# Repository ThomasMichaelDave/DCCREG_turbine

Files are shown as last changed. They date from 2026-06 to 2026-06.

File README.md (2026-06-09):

# Variable Capacitor → Symmetric Bennet Doubler

A browser-based design tool. A parametric **sectored-disc + ring** capacitor plate, whose geometry, plate gap, and dielectric set the **rotor-capacitance extremes** that drive a **Symmetric Bennet Doubler** switched-capacitor solver. One self-contained `index.html`, no build step.

> **Status.** Host doubler simulator: working, self-tested. **Block C-I** (geometry → rotor-cap front end): *implemented and self-tested* in `index.html` — see `docs/` for the brief and `CHANGELOG.md` for the audit trail.

---

## Working discipline

Every substantive claim in the docs (and modelling choices in code comments) carries a tier tag:

- **[OC] Operational Core** — standard, derivable physics/math; true independent of this project.
- **[IR] Interpretive Reading** — a modelling / engineering choice; internally consistent, chosen rather than forced.
- **[RH] Resonance / Heuristic** — suggestive, not load-bearing.

Keep the tiers honest; do not let **[RH]** drift into **[OC]**. Correct openly when rigor demands and record it in `CHANGELOG.md`.

The *methodology* (tier tags, versioned consolidation, open-fork tracking, symbol hygiene, handoff README) is adapted from the **DCCREG programme conventions**. **The physics in this repo is entirely mainstream** — parallel-plate capacitance, rotary variable capacitors, and the Bennet charge doubler. **No DCCREG theory is included or required.**

---

## Repo map

| Path | Role |
|:--|:--|
| `index.html` | The app — Symmetric Bennet Doubler 4-node simulator (**host**; Blocks C-I and M extend it) |
| `docs/brief-blockC1-geometry-to-rotorcap.md` | Implementation brief for the geometry → rotor-cap module |
| `docs/commutator-design.md` | Switching design — physical realisation of the solver's diodes D1–D4 (rotary commutator); geometry frozen, transfer model open |
| `docs/brief-blockM-rotor-mechanical-core.md` | Implementation brief for the rotor mechanical core (quadricone + shaft + void + disc) |
| `docs/brief-blockR-central-resonator.md` | Implementation brief for the central resonator (conical coil + inter-electrode capacitor) |
| `docs/report-tool-functioning.md` | Standalone functional report on the whole tool |
| `reference/SectoredDiscCalculator.jsx` | Area-math source to **port** into `index.html` (reference only — not built/served) |
| `CONVENTIONS.md` | Epistemic tags + symbol-hygiene table + host-field-id mapping |
| `CHANGELOG.md` | Human-readable audit trail (git owns the authoritative history) |
| `CLAUDE.md` | Handoff + guardrails for the Claude Code agent |

## Read order (fresh agent or contributor)

`README.md` → `CONVENTIONS.md` → `docs/brief-blockC1-geometry-to-rotorcap.md` → `index.html` (host) → `docs/commutator-design.md` (switching realisation) → `reference/SectoredDiscCalculator.jsx` (math to port).

## Run

Open `index.html` in any modern browser. No build, no server, no dependencies. State is shareable via the URL hash ("copy share-url").

## Current task

Blocks **C-I** (geometry → rotor caps) and **M** (rotor mechanical core) are implemented in `index.html`. Both follow the producer/consumer discipline: C-I drives the rotor caps; M is an independent producer (geometry + cross-section readout) that never touches `solveDoubler4`.

## Verification

The page self-tests on load (engine badge + expandable self-test table). The gate is deterministic: the four original solver tests + swap symmetry, the C-I plate tests (dry-air ε_r ≈ 1.000576; fixed-geometry capacitance), and the Block M tests (`hubDia = 197 mm`; void-partition identity; `keyLenFor(35) → DIN 56`) must all pass — badge reads "engine verified".

## Versioning policy

Git owns history. `CHANGELOG.md` is the human-readable audit trail. **Flat filenames — no `_vNN` suffixes and no in-file revision tables** (git replaces both). Conventional-commit style suggested: `feat:`, `fix:`, `docs:`, `test:`, `refactor:`.

## Open forks

Carried from brief §7: field-range policy (raise-max vs clamp-and-warn); hash round-trip for non-numeric controls; solid-dielectric rotary realisability; optional θ-sweep visualisation; dielectric-strength / safe-voltage bound (the genuine next block); fringing correction.

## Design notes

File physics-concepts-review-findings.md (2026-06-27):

# Findings — physics-concepts review → **REPO MAINSTREAM · ION-SIPHON HAS ONE LOAD-BEARING CONSERVATION GAP**

**Branch** `claude/physics-concepts-review-wp81n4`.
**Scope:** scrutinise the load-bearing physics against mainstream electromagnetism / thermodynamics.
Two bodies reviewed: (1) the existing repo (Bennet doubler + variable-capacitor front end + energy-balance
findings); (2) the uploaded `ion_siphon_package.zip` (electret-capillary ion siphon).
**Tier tags** as in `CONVENTIONS.md`: **[OC]** standard physics · **[IR]** modelling choice · **[RH]** heuristic.

**Verdict line:** the repo's electrostatic-machine physics is **mainstream and internally honest**; the
ion-siphon derivation is mostly sound **but its "continuous mode" rests on a non-depleting electret driving a
steady closed-loop current — which a conservative field cannot do.** That single move, taken literally, is an
over-unity element. Everything else in the ion-siphon doc is either correct or already flagged as open.

---

## 1. The existing repo — passes mainstream scrutiny

### 1.1 Bennet doubler / variable capacitor [OC]
The host (`index.html`, `solveDoubler4`) is a symmetric Bennet charge doubler driven by a rotary variable
capacitor. This is textbook electrostatics: the voltage gain is paid for by **mechanical work** done moving
the plates apart against electrostatic attraction at (near-)constant charge (`W = ½Q²·Δ(1/C)`). No free
energy is claimed. The Block C-I geometry→capacitance front end (parallel-plate `C = ε₀ε_r A/g`, triangular
overlap `f_ov(θ)`, Smith–Weintraub moist-air `ε_r`, Buck saturation pressure) is standard and correctly
cited. ✔

### 1.2 Energy-balance findings — honest, and a good positive control [OC]
`energy-balance-findings.md` is the right kind of work:
- The per-cycle identity `W_mech = ΔE_stored + E_tax` closes to **1.4×10⁻¹⁶** (machine precision) — i.e. the
  charge-law `z` campaign is confirmed by an independent **energy** conservation law.
- It surfaces the **equalization tax** (61.4 % of shaft work): the two-capacitor paradox `½·C₁C₂/(C₁+C₂)·ΔV²`
  dissipated at every diode merge **even with ideal diodes**. Correctly identified, correctly quantified.
- It explicitly refuses to call `E_tank/W_mech > 1` an efficiency ("a deliberate tell, surfaced not
  smoothed"). That is exactly the discipline a conservation review wants to see.

**Conclusion for the repo:** no over-unity claim. The machine is a shaft-driven electrostatic generator whose
output is bounded by, and accounted against, the mechanical input. Mainstream. ✔

---

## 2. The ion-siphon package — detailed scrutiny

### 2.1 What is correct [OC]
- **Kinetic (inertial) inductance `L = mℓ/(ne²A)`.** Genuine and correctly derived from carrier momentum
  (½·nmAℓ·v² ≡ ½LI², I = neAv). This is real textbook physics (kinetic inductance of a charged carrier
  column). ✔
- **Dose mode is exactly right.** With no leak, the collector charges until its back-EMF cancels the drive
  and the device stops after delivering `Q_max = C_k V_e`. This is just an electret discharging its stored
  field energy into a capacitor — completely mainstream, energy-bounded, and honestly stated. ✔
- **Steady-state algebra is internally consistent.** `I_ss = V_e/(R+R_leak)`, `V_sc,ss = V_e R_leak/(R+R_leak)`,
  and the characteristic equation `L C_k s² + (R C_k + L/R_leak)s + (1 + R/R_leak) = 0` are algebraically
  correct *for the circuit as drawn*. The problem is not the algebra; it is what `V_e` is allowed to be.
- **Honesty notes are present and good:** §3.3 (a solid film can't be rotated against in a rotary varcap),
  §6.2 + the MIGRATION "OPEN" block (axial poling vs central-null coupling is *stated, not solved*). These
  are correctly tiered as unresolved. ✔

### 2.2 LOAD-BEARING PROBLEM — a static electret cannot sustain a steady closed-loop current

The schematic (`ion_siphon.svg`) and §4 make the topology explicit:

```
atmosphere (ref at ∞) ── C_atm ──[ electret V_e + L + R ]── collector ── C_earth ── earth (common return)
                                                                  └────── R_leak ──────┘
```

**Earth is the common return, so the loop is closed**, and the electret `V_e` is the *only* source in it.

An electret is a frozen **electrostatic** polarization. Its field is conservative:
$$\oint \mathbf{E}\cdot d\boldsymbol{\ell} = 0 \quad\text{for any closed loop. [OC]}$$
The net EMF a static electret can contribute around a closed circuit is therefore **exactly zero**. It is not
a battery: a battery has a non-electrostatic charge-separating mechanism that does work `qV` on each carrier
every lap, which is what lets a battery sustain `I²R` dissipation indefinitely. An electret has no such
mechanism. So:

> **Continuous mode (steady `I_ss` flowing "indefinitely, limited only by the electret lifetime") dissipates
> `I_ss²(R+R_leak)` forever from a source that, by construction, "sources essentially no net charge" and "does
> not sag under load." A non-depleting source delivering sustained power is an over-unity element. [OC]**

The doc reaches this position by a specific substitution. In **Stage I** it correctly notes the passive head
`(V_s − V_k)` *bleeds down* as charge transfers — reservoirs deplete, exactly as a real open siphon drains
its upper reservoir. In **Stage II** it *replaces* that depleting head with an electret `V_e` "that no longer
decreases with delivered charge." That replacement is the unsupported step: it converts a correctly-depleting
drive into a perpetual one and never writes the continuous-mode **energy** balance to check it.

**The correct physics (two legitimate readings, neither matching the doc's framing):**
1. **The electret is the energy store ⇒ it depletes.** The energy for sustained `I²R` comes from the
   electret's stored field/polarization energy, which is finite. Then `V_e` is *not* constant, `I_ss` decays,
   and the device is just a slow version of dose mode. "Continuous, limited only by lifetime" is then
   misleading: the lifetime *is* the energy budget, not a separate material-aging footnote. This collapses
   "continuous mode" into "dose mode with a leak that drains the store faster."
2. **The atmosphere–earth potential difference is the real drive ⇒ *it* depletes (or is externally
   replenished).** The global atmospheric electric circuit (~100 V/m fair-weather field, maintained by
   thunderstorms — i.e. ultimately solar) is a genuine, mainstream energy source. A device tapping it is an
   atmospheric-electricity harvester, not perpetual motion — but then the sustained energy comes from `C_atm`/
   `C_earth` reservoirs bleeding down (**Stage I**, which the doc discarded), **not** from the electret. The
   electret would merely bias the geometry, not power the flow.

Either way, the load-bearing claim — *electret as a non-depleting drive sustaining steady current* — is the
one thing that cannot stand. The doc's own dose-mode result (`Q_max = C_k V_e`) and its depolarization caveat
already contain the correct, conservation-respecting physics; the **continuous-mode framing contradicts
them.** [OC]

Supporting real-world check: this is exactly why **electret microphones** work — the electret holds a bias
while drawing **negligible steady current** into a high-impedance gate. Draw sustained current and the
electret simply discharges. That commercial device is the empirical statement of the limit above.

### 2.3 SECONDARY PROBLEM — "uniformly polarized shell ≡ uniform surface charge" is not an identity

§3.2 claims: *"A uniformly polarized spherical shell — equivalently, a uniform surface charge on a sphere —
produces zero electric field everywhere in its interior."* These are **not** equivalent. [OC]
- A **uniform monopole surface charge** `σ = const` on a sphere → zero interior field (shell theorem). ✔
- A **uniform polarization** `P` produces bound surface charge `σ_b = P·n̂ = P cosθ` (a *cosθ*, dipole-like
  distribution), and a uniformly polarized solid sphere has a **uniform, non-zero** interior field
  `E = −P/(3ε₀)`. ✘ for "zero interior."

So the "interior field-null" datum that §3.2/§6.1 lean on does **not** follow from an electret's (polarized)
charge state — it would require an engineered uniform *monopole* surface charge, which an electret is not.
This is the same tension the doc itself flags in §6.2 (axial poling vs central null), so it is not fatal — but
the stated equivalence is a real conceptual conflation and should be corrected, not used as a clean given.

### 2.4 Framing observation [RH]
Both the repo README ("the physics in this repo is entirely mainstream … no DCCREG theory required") and the
ion-siphon MIGRATION §6 ("strict physics only … if a framework-tagged companion is wanted later, it should be
a separate document") position these as the *mainstream-presentable face* of a larger framework. That is fine
as a discipline — but it raises the bar: a doc that advertises "strict physics only" must not contain a
non-depleting source. §2.2 is precisely the kind of claim that the strict-physics framing is supposed to
exclude, and it slipped through.

---

## 3. Recommendations (no code changed; review only)

1. **Ion-siphon §3.1/§5.2/§8 — write the continuous-mode energy balance.** State plainly that sustained
   `I_ss` is paid for either by the electret's finite stored energy (then `V_e` decays and "indefinite" is
   wrong) or by a depleting/replenished atmosphere–earth reservoir (then re-instate the Stage-I bleed-down
   and credit the atmosphere, not the electret). Drop "non-sagging source + steady current indefinitely" as a
   joint claim. [OC]
2. **Ion-siphon §3.2 — fix the polarization/surface-charge equivalence.** Either specify an engineered
   uniform monopole surface charge for the null, or acknowledge the polarized electret gives a uniform
   non-zero interior field and treat the null as an unsolved geometry target (consistent with §6.2). [OC]
3. **Keep** the dose-mode result, `L = mℓ/(ne²A)`, the kinetic-inductance derivation, and all the existing
   honesty/open-problem flags — those are sound. ✔
4. **Repo:** no action needed for conservation; it is mainstream. The natural next block remains the
   dielectric-breakdown / safe-voltage bound already listed as an open fork. ✔

**Bottom line:** the repo is clean. The ion-siphon "continuous mode" is the one place where mainstream physics
is violated — by treating an electrostatic electret as a perpetual EMF. Recast it as energy-bounded (dose
mode / depleting reservoir) and the whole package becomes mainstream-consistent.

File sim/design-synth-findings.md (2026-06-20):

# Findings — DESIGN-SYNTH: a constrained dimension-chooser

**Branch** `design-synth` (off `torque-sim` — the brief's `design-optimize` base does not exist as a
branch; `torque-sim` carries the frozen solvers, the validated profiles, and the established machine,
and the "rules" are **reconstructed from the campaign's established results**). **Verdict:**
**`SYNTH-FEASIBLE`** — Claude Code chose every dimension, **every invariant held**, the conservation
guard **closes and can fail**, and the tool reports **which rule binds** each objective. The
infeasible-goal probe returns `SYNTH-INFEASIBLE` **with the named blocker**, exactly as specified.

**The principle, realized.** Dimensions are decision variables; the rules and derivations are hard
constraints. The synthesizer **calls** the frozen solvers (`doubler_core` z/η, `shuttle_core` W_coll)
per candidate — it never re-derives, fits, or overrides them — so flexibility can only move within the
feasible region the invariants define. The frozen solvers keep *intent* and *geometry* from ever
trading places.

> **r0.2 correction (bus margin) — `CANARY-RESTORED`.** r0.1 reported the rotor diameter as the
> *active-band* diameter (`r_out × 2`) with **no bus margin**, and computed the rim at `r_out` — so the
> established machine "reproduced" at 774 mm instead of its real **~982 mm** rotor (R387 active-band
> outer → **R491 rotor outer after the 27 % bus** → R500 plate edge), and I9's rim margin was
> overstated. The synthesis *logic* is unchanged (z-band, bindings, infeasible-naming are ratio-based,
> bus-independent). Fixed: `BUS_MARGIN = 0.27`, every reported diameter = `2·r_out·(1+bus)`, the rim is
> at the **rotor body** (R491), and the **canary now asserts the rotor diameter** (~982 mm) — it
> correctly **fails at 774 mm if the bus is dropped** (verified). Corrected table:
>
> | item | r0.1 (no bus) | r0.2 (corrected) |
> |---|---|---|
> | established rotor (canary) | 774 mm | **983 mm** ✓ (assertion live, [960,1010]) |
> | min_diameter @ 15 kV | 500 mm | **635 mm** (r_out 250) — bound by I3 |
> | max_eta | 700 mm | **889 mm** (r_out 350) — bound by I3 |
> | max_rpm rim @ 6000 rpm | 157 m/s | **199 m/s** (at the 200 m/s wall) |
> | max_rpm I9 ceiling | "9000 rpm" | **~6000 rpm** (rim binds at the rotor radius) |
>
> The infeasible probe is re-stated in the corrected definition: "rotor dia ≤ 300 mm" is now
> `r_out ≤ 118 mm` (was 150); blocker unchanged (z → 1.0, **I3**). z/η and all binding constraints are
> identical to r0.1. The synthesizer's diameters are now comparable to the parametric reference, the
> HTML sizer, and the worked example (all apply bus ≈ 0.27–0.29).

---

## §5 named checks

| # | check | result |
|---|---|---|
| 1 | frozen empty-diff; **solvers called (not re-implemented)** per candidate | ✓ `doubler_core`/`eb` for z/η, `island_charging`(frozen shuttle) for W_coll; cached by scale-free ratio |
| 2 | **regression anchor** — established ~1000 mm / 15 kV reproduces | ✓ **C1_max 280 pF** (forward model exact), z **1.334**, η **0.386**; feasible on all 10 invariants |
| 3 | chosen objective + optimal free-var set | ✓ 3 objectives (min-diameter, max-η, max-rpm) below |
| 4 | **full §2 battery passes; binding invariant named** | ✓ I3 (size, η), I9 (rpm) — distinct, meaningful |
| 5 | **I1 conservation closes + +5 % trip fires** | ✓ resid **≤1.3×10⁻¹⁶**, +5 % source perturbation **trips** (non-tautological) |
| 6 | design sheet + compliance table | ✓ `synth_design.csv`, `synth_compliance.csv` |

## The invariant battery (reconstructed from the campaign)

| # | invariant | encoded as | source block |
|---|---|---|---|
| **I1** | conservation, real | per-cycle ledger closes **and** +5 % source-term perturbation trips it | torque-sim |
| **I2** | frozen-solver authority | z/η from `doubler_core`; W_coll from `shuttle_core` — called, never substituted | foundation |
| **I3** | scale-free z | z ∈ **[1.20, 1.45]** (device 1.203 … wide 1.438); ratios only | doubler anchors |
| **I4** | insulate-first | gap V_bd(vacuum)=60·g^0.6 kV > V_target; septum 5 kV/mm derated; split-coil antinode out | coil-topology / freeze |
| **I5** | tax managed | η ≥ 0.15 (else stage N) | energy-balance |
| **I6** | parasitic floor | C_par ≥ 20 pF; slack = modulation margin (C_max−C_par)/C_par | S-blocks |
| **I7** | motor matched | output ≤ pump net; f_res = PRF (300 Hz); high-Z spectator at f₀ | S7 / full-sim |
| **I8** | DC-trapped tank | tank held DC, tan-δ duty-limited (not the voltage lever) | S8 (53 W debunk) |
| **I9** | mechanical | rim < 200 m/s (soft 150); supercritical; vacuum ≤ 10 Pa | freeze / full-sim |
| **I10** | shuttle integrity | island strike < node ceiling (21 kV); collapse reaches V_strike from V* | geom-validate |

## The regression anchor (the canary)

The established machine (r_in 95, r_out 387, g_v 7 mm) synthesizes to **C1_max = 280 pF** (the forward
geometry model is exact), **z 1.334 / η 0.386** (frozen solver), rotor **774 mm diameter**, **feasible
on all 10 invariants**. The least-slack invariant is **I10** (the shuttle strike-vs-ceiling margin,
20 vs 21 kV, slack +0.05 — the machine's tightest rule). **The coupling is intact** → no synthesis is
believed until this passes.

## The synthesized designs (Claude Code chose; the rules held)

| objective | optimal dimensions | z | η | **binding constraint** |
|---|---|---|---|---|
| **min diameter** @ 15 kV | dia **500 mm** (r_out 250), g_v 3 mm, C_min 20 pF | 1.272 | 0.441 | **I3 scale-free z** — shrinking to dia 400 collapses the modulation (z < 1.20) |
| **max η** (min tax) | dia 700 mm, g_v 5 mm, C_min 50 pF | 1.225 | **0.526** | **I3 scale-free z** — pushing η higher (lower modulation) drives z to the 1.20 floor |
| **max rpm** | dia 500 mm @ **6000 rpm** (rim 157 m/s) | 1.272 | 0.441 | **I9 mechanical** — 9000 rpm would exceed the 200 m/s rim limit |

**The single most useful diagnostic — the binding constraint — is distinct per objective:** the
**doubler z-derivation (I3)** is what limits the *small* and the *efficient* designs (you cannot
shrink the plates or trade modulation for efficiency without the scale-free z falling out of its
validated band), while **mechanics (I9)** is what limits *speed*. The tool found these by perturbing
the objective's variable toward improvement and reporting the rule that fails — the *active*
constraint, not merely the globally-tightest one.

## I1 — a conservation guard that can fail (carried from torque-sim)

The per-cycle ledger closes (residual ≤1.3×10⁻¹⁶) **and the mandatory +5 % self-test trips it**: a
+5 % perturbation of the source term moves the residual off zero (the destinations are independent
models using the *nominal* energies, so they don't track the perturbed source). As in torque-sim, the
**discriminator is the trip, not the baseline magnitude** — the guard is a genuine check, not an
identity. Every reported feasible candidate passes it.

## The infeasible-goal probe (a result, not a failure)

Demanding a **tiny rotor (dia ≤ 300 mm)** at 15 kV returns **`SYNTH-INFEASIBLE`** over the grid (0/6
feasible), and **names the blocker: I3 (scale-free z)** — at r_out 150 the C_max (62 pF) approaches
the parasitic floor (20 pF), the modulation collapses to ~2, and **z → 1.000 (no pumping)**. The goal
is impossible *without relaxing a stated rule*: a higher-z ratio family, a smaller stray floor, or
accepting a lower z. The tool says **which** — the prize the brief specified.

## Verdict + what it means

**`SYNTH-FEASIBLE`** — the synthesizer is the standing bridge between *intent* and *geometry*: state a
goal, get a dimensioned design **guaranteed by construction to honor every derivation and rule** the
campaign established. The flexibility lives in the dimensions; the discipline lives in the invariants;
and the frozen solvers keep the two from trading places. The **binding constraint** per objective is
the actionable output — it names the rule to relax if you want to push further (I3 for size/efficiency,
I9 for speed).

## Deliverables

`sim/design_synth.py` (the synthesizer: free-variable search, the §2 invariant battery with
frozen-solver calls, the configurable objective, the *active*-binding-constraint reporter; self-tests:
the regression anchor + the +5 % conservation trip) · this findings doc · `synth_design.csv` (the
chosen dimensions per objective + binding constraint) · `synth_compliance.csv` (per-invariant
pass/slack at the anchor) · `synth_feasible.png` (the I3 z-band edge vs rotor diameter — the
size-limiting derivation, with the optima marked). Frozen empty-diff asserted. **Not merged** — the
synthesized designs feed the DXF/deck only on TMD's approval.

### Roadmap (brief §9)

`SYNTH-FEASIBLE` → **proposed dimensioned designs** with their binding constraints and a clean
conservation guard. **TMD reviews**; on approval a chosen design feeds the **concentric-pole drawing**
(optimized motor geometry — which also closes the torque-sim's `SELF-SPIN-INDETERMINATE` by making
`L(θ)` geometric) and a DXF/deck update. `SYNTH-INFEASIBLE` → the named blocking invariant tells you
exactly which rule the goal violates — relax it deliberately and re-run. The synthesizer is the
intent→geometry bridge for the remaining design arc.

> **Base-branch note.** The brief branches off `design-optimize`, which has not been built in this
> repo (no numbered-rules doc / HTML-sizer-as-rules artifact exists). I branched off `torque-sim`
> (carries the frozen solvers + validated profiles + established machine) and **reconstructed the
> invariant battery from the campaign's established results** (cited per invariant above). If a
> formal `design-optimize` rules block is intended first, this synthesizer drops onto it unchanged —
> the invariants are already encoded as callable checks.

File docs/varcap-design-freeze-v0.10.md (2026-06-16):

# Varcap-machine — design freeze v0.10 (temporary)

**Status:** temporary freeze for github. Geometry + cap set validated; C_R now pinned via the 12 mm disc.
Six spark gaps placed; **backstops (BS3/BS4) the only missing gap geometry**. Mainstream EE only — no
DCCREG theory in this project.

---

## 1. Design concept

A high-voltage **rotary electrostatic generator**: a symmetric **4-node Bennet voltage doubler** (solver
nodes 1–4 stator; nodes 5/6 the two **co-rotating** rotor halves) with **flying-bucket ("shuttle") charge
transfer** via floating island bars (nodes 7/8), and **rotary, alignment-gated self-break spark-gap
commutation** (no diodes, no triggers, no slip rings — direction comes from timing).

The doubler pumps the rotor toward ~20 kV. Per fire event an island bar dumps its charge through a **fire
gap** into a central **C_R ∥ L_R resonator tank** — C_R is the rotor-rotor capacitance across a garolite
septum; L_R is a **conical coil on the bicone hub surface** — which rings at **f₀ ≈ 637 kHz**. An **upstream
two-tier clamp** (soft glow governor + hard crowbar) holds the tank at the **15 kV** operating point.
12 sectors, 6 alternating active, **6 pump cycles per revolution**; spin-up by a switched-reluctance motor
(quadricone steel cores). Reach is **single-kick energy balance** (½·C_R·V²), Q-robust and f₀-independent.

## 2. Node map

| Node | Body |
|---|---|
| 1–4 | stator (C1, C2 stators; Ca, Cb, Cx pickup electrodes) |
| 5 / 6 | shaft A / shaft B rotor halves (co-rotating, locked through the central hub coupler) |
| 7 / 8 | island bar set on B / on A (floating, isolated from node 5) |

## 3. Capacitor set (everything that feeds the simulator)

| Cap | Electrodes (radii, mm) | Gap / dielectric | Sectors | Value | Tier |
|---|---|---|---|---|---|
| C1 | ND1 r387 ↔ ND5 rotor r387 | 7.0 mm air | 6 alt | 16–280 pF | [OC] |
| C2 | ND4 r387 ↔ ND6 rotor r387 | 7.0 mm air | 6 alt | 16–280 pF | [OC] |
| Ca | ND1 ↔ ND2 (r175) | 4.5 mm mica | — | 309 pF | [OC] |
| Cb | ND3 (r110–175) ↔ ND4 | 4.5 mm mica | — | 309 pF | [OC] |
| Cx3 | ND7 bars r75–350 ↔ ND3 pickup r58–350 | 3.0 mm air + 0.3 mm mica/face | 6 alt | 8–648 pF | [OC] |
| Cx4 | ND8 bars r75–350 ↔ ND2 pickup r58–350 | 3.0 mm air + 0.3 mm mica/face | 6 alt | 8–648 pF | [OC] |
| **C_R** | ND5 ↔ ND6 (electrode r387) | **12.0 mm garolite** | half-ann | **789 pF** | [OC] |
| L_R | 36-turn Cu 3/1 mm capillary, conical, bicone hub (coil r28→76, ~108 mm axial) | — | — | 79 µH | [OC] |

Resonator: **C_R = 789 pF, L_R = 79 µH → f₀ ≈ 637 kHz, Z₀ ≈ 316 Ω**, Q sweep 320/500/900.
*(C_R was pinned by choosing the disc thickness: 12 mm garolite at the r387 electrode → 789 pF. This is the
matched/comfortable point — see §4.)*

## 4. Pump / reach

- Pump per-cycle gain **z ≈ 1.307** (grown 648 pF island; **unchanged by C_R** — the pump shorts the 5–6
  rail, so C_R does not feed z). Galvanic ceiling 1.334, island ledger clean.
- Reach floor (½·C_R·V², 15 kV / 789 pF) = **89 mJ**.
- M2 island-dump transfer η = 4·Cx·C_R/(Cx+C_R)² = **99 %** (648/789 nearly matched).
- **Fire window:** single-kick reach requires island fire **≥ 16.6 kV** (delivers 89 mJ at η 99 %); the
  C1/C2 7 mm air gaps cap the island at **~21 kV**. Window **16.6–21 kV (4.4 kV margin)** — comfortable.
- **S2 should be re-confirmed at C_R = 789 pF** (favourable: lower floor, better match than the 960 pF run).

## 5. Spark-gap + clamp spec

Air-breakdown gradient: **3.0 kV/mm** sphere-gap (bench-calibrate vs IEC 60052). Each gap ×6 (every 60°).

| Gap | Path | Station | Radius | Spacing | Electrode | DXF |
|---|---|---|---|---|---|---|
| SG1 | node 2 → rail | 3.00° | C1/Ca disc | ~5–6 mm | 12 mm W-Cu sphere | **placed** |
| SG2 | node 3 → rail | 33.00° | C2/Cb disc | ~5–6 mm | 12 mm sphere | **placed** |
| SG3a | node 1 → bar | 7.20° | ~r340–350 | ~4.5–5 mm | 12 mm sphere | **placed** |
| SG3b | bar → node 3 (FIRE) | 16.05° | outer ~r340–350 | ~5.5 mm* | 12 mm sphere | **placed** |
| SG4a | node 4 → bar | 37.20° | ~r340–350 | ~4.5–5 mm | 12 mm sphere | **placed** |
| SG4b | bar → node 2 (FIRE) | 46.05° | outer ~r340–350 | ~5.5 mm* | 12 mm sphere | **placed** |
| BS3 | backstop (misfire) | **19.0°** | outer ~r350–380 | 0.6× strike | 20–30 mm smooth | **TODO** |
| BS4 | backstop (misfire) | **49.0°** | outer ~r350–380 | 0.6× strike | 20–30 mm smooth | **TODO** |
| Governor | clamp (upstream/island) | — | island side | — | smooth, 15 kV | [IR] |
| Crowbar | clamp (last resort) | — | 5–6 void | — | smooth hollow sphere, 16 kV | [IR] |

*Fire-gap spacing relaxes with the wider window: SG3b/SG4b strike target ~16.6–20 kV island → ~5.3–6.4 mm.
Load/return spacings still need the pump's absolute node voltages. Radial bands governed by **quench** (push
outboard), bounded by the island r350. Timing: 30° SG3↔SG4 stator offset; 12-sector grid @30°; 6 bars/set.

## 6. Materials

Switching electrodes: tungsten / W-Cu spheres. Glow electrodes (backstops, governor): smooth large-radius.
Void-facing surfaces: Macor. C_R septum: **12 mm garolite** (15 kV/12 mm = 1.25 kV/mm holdoff). Ca/Cb/Cx
barriers: mica. Coil: copper 3/1 mm capillary. Quench: radial forced-air impeller with the disc's pumping.

## 7. Freeze status

- **Frozen / validated:** node map, cap geometry & values, **C_R = 789 pF pinned (12 mm disc)**, resonator
  C_R∥L_R, pump z, firing-station angles, 6 spark gaps placed, clamp architecture, materials.
- **Open before a *permanent* freeze:** (a) BS3/BS4 backstop markers + electrode geometry (§5); (b) one
  combined sim pass — re-confirm S2 reach at C_R = 789 pF (entry gate), then S3 spark tier at the real gaps
  (strike / quench / integrated reach).
- **Producer/consumer:** frozen solvers (`doubler_core`, `shuttle_core`) untouched; this freeze is
  documentation + DXF.

## 8. Artifacts

`varcap-nodeanalysis-template-r0_10_TMD_layout.dxf` · this document · the S2 coupling findings/code · the
gap-hardware spec.

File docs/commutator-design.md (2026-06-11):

# Rotary Commutator — Switching Design

**Status:** [IR] Geometry frozen; transfer model open. Physical realisation of the
solver's ideal diodes `D1–D4`; `solveDoubler4` is unchanged and remains the ideal-diode
ceiling. Mainstream EE only — no DCCREG theory.

## 1. Purpose

How the doubler's switches (the solver's ideal diodes `D1–D4` in `index.html`) are
physically realised: a **rotary, contactless, mechanically-timed electrostatic
commutator**. Floating rotor bars bridge stator electrodes across a double gap during
geometric alignment — influence-machine lineage (Wimshurst, Bonetti, Kelvin, Van de
Graaff): direction comes from *timing*, not from a diode or a trigger. This document is
the physical layer plus its real-world derating; it does **not** change the engine. **[IR]**

## 2. Switch ↔ diode mapping

The 4-node solver in `index.html` is authoritative. Physical spark-gap aliases:

| Solver diode | Physical switch | Path | Realisation |
|:--|:--|:--|:--|
| `D1` (2→0) | SG1 | 2 → rail | single gap to the resonator rail |
| `D2` (3→0) | SG2 | 3 → rail | single gap to the resonator rail |
| `D3` (1→3) | SG3 | 1 → 3 | double gap over a floating bar |
| `D4` (4→2) | SG4 | 4 → 2 | double gap over a floating bar |

**Ground ≡ resonator rail.** The solver's ground (node 0) is physically the resonator
rail (nodes 5–6, coil `L_RES`/`L1`). At PRF, `L1` is a near-short — the repo's
"L1-is-a-short-at-PRF" argument (learn stage 03) — so the 4-node, ground-referenced model
is valid. The 5–6 resonant swing is the measurable output, treated separately from the
pump model. The cross-couples `D3`/`D4` are node-to-node and map to SG3/SG4 unchanged.
**[OC for the L1-short; IR for the physical layering]**

**Resonator inductance.** `L_RES` (= `L1`, the coil across nodes 5–6) ≈ **123 µH** —
the value Block R's `resonatorCore` computes for the default coupled tank (also recorded
in `docs/report-external-review.md`; the capillary self-test config gives ≈ 131 µH).
TMD-checked and authorised 2026-06-11. **[IR]** This is the value downstream simulations
(e.g. `shuttle_core.py`) must cite for the 5–6 resonator branch; at PRF it is the near-short
above, so it bears on the 5–6 ring dynamics, not the charge-pump verdict.

## 3. Switching regime (frozen)

| Decision | Choice | Consequence |
|:--|:--|:--|
| Trigger regime | Hybrid: alignment gates a self-break | Timing geometric (drift-free); firing voltage = self-break (drift demoted to operating-point) **[IR]** |
| Coupling | Momentary bridge — both gaps fire together when aligned | Bidirectional *within* the window → rectification comes from timing the window to the favourable-polarity half **[IR]** |
| Multiplicity | 6 bars per cross-couple (12 total) | 6× charge **throughput** per couple — not 6× voltage **[IR]** |

Alignment (minimum-gap instant) sets *when* breakdown is possible — pure rotor geometry,
drift-free, measurable. The self-break sets the *voltage*; in a threshold-driven pump that
drift only nudges the operating point. The firing *angle* is the intersection of two
rotor-deterministic curves (rising V vs gap length), so jitter stays low. **[OC]**

## 4. Conduction pairing (solver-verified)

Extracted from `solveDoubler4`'s phase logic at the device point:

- Phase B (C1→min): `D2` + `D4` conduct.
- Phase A (C2→min): `D1` + `D3` conduct.

So the switches group **by transfer-cap branch**: `{D1,D3}` (Ca, sources nodes 1,2) and
`{D2,D4}` (Cb, sources nodes 3,4) — i.e. SG1+SG3 and SG2+SG4. This matches the drawn
timeline (1,3)/(2,4) and the `L_A↔Ca / L_B↔Cb` motor wiring. **The solver is the arbiter;
do not record a different pairing.** **[OC]**

## 5. Physical geometry (frozen)

- **Two mirror bar sets:** one 6-arm set at the top of the rotor, one at the bottom, about
  the central resonator hub — for rotor balance and to match the doubler's C1↔C2 symmetry.
  Top set serves SG3 (1→3); bottom serves SG4 (4→2). **[IR]**
- **In-plane bridging:** each bar bridges two stator electrodes within its own plane. The
  cross-couple sinks — node 3 (SG3) and node 2 (SG4) — are routed **across the ecliptic
  (mid-plane)** on the stator leg frame to reach the opposite plane. 12 in-plane bridges
  total, 6 per cross-couple.
- **Leg frame** (counter-rotating with the stator) carries **both** the 12 motor C-EMs
  **and** the cross-ecliptic HV routing for nodes 2, 3.
- **Floating bars:** one per active sector (6 per set); isolated from node 5; on the rotor;
  each a double (series) gap with a floating midpoint.
- **Returns** SG1/SG2 are single gaps straight to the rail — no floating bar (the rail is
  on the rotor). SG1 rides the C1/Ca disc with SG3; SG2 the C2/Cb disc with SG4.
- **The 30° offset lives only in the stator sector discs** (one sector pitch, 360°/12). The
  top and bottom **bar sets are axially aligned**; the firing offset comes from the stator
  electrode positions. Do not also offset the bar sets, or the offset doubles to 60°.

## 6. Timing (frozen)

- 30° = sector pitch = C1/C2 antiphase pump offset = stroke offset. Commutator timing is
  **inherited from the varicap sector geometry — no separate clock;** favourable-polarity
  phasing is automatic. **[OC]**
- C1's full max→min→max spans 60° → 6 pump cycles per revolution, two strokes 30° apart.
  SG3 fires 6×/rev; SG4 6×/rev, offset 30°.
- **Relative speed governs** alignment, sweep speed, and firing rate: bars on the rotor,
  commutator electrodes on the counter-rotating leg frame → the sum of both rates. The
  `PRF = ⌈Nsec/2⌉·RPM/60` (F6) must use the **relative** RPM. **[OC]**
- Favourable half ≈ 30° (≈ 1.7 ms at the design relative rate); the arc must quench inside it.

## 7. Quench (frozen approach)

The arc **must extinguish before the varicap polarity reverses**, or it back-conducts and
dumps the pumped charge — the make-or-break constraint. **[OC]** Quench by motion (larger
transfer radius → faster sweep, ionisation spread over more area) plus forced air (radial
"Dyson"-type impeller). Run the flow **with** the disc's centrifugal pumping — axial intake
through the clocking stack, exhaust at the rim — not against it. The impeller is a parasitic
windage load on the spin-up motor (stage D torque budget). **[IR]** Margin: ~1.7 ms window
vs µs-to-sub-ms arc blow-out — comfortable. **[OC]**

## 8. Constraints & consequences

| # | Item | Tier | Note |
|:--|:--|:--|:--|
| C1 | Arc quench < favourable half | [OC] | Make-or-break; verify in model and on bench |
| C2 | PRF basis = relative (counter-rotating sum) RPM | [OC] | Check the `PRF`/System inputs use the relative rate |
| C3 | Erosion is real (spark chosen) | [IR] | Distributed by 6 bars + radius + airflow + W/W-Cu. Gaps widen over life → operating voltage creeps; timing unaffected (geometric). Maintenance interval. |
| C4 | Series double-gap strike voltage less predictable | [IR] | Two Paschen curves + floating-midpoint stray C. Tolerable: timing geometric, level non-critical. |
| C5 | Floating-bar DC charge accumulation | [IR] | May need a weak bleed to a reference to stop slow charge-up. |
| C6 | HV insulation coordination | [IR] | Nodes 2,3 carry pumped HV across the leg frame beside lower-voltage C-EM windings — real creepage/clearance margin required. |
| C7 | Parasitic capacitance, asymmetric | [IR] | Cross-ecliptic runs add stray C on 2,3 only → feeds `Cpar`, asymmetrically; slightly tilts the C1↔C2 symmetry the solver assumes. |
| C8 | No accidental cross-bridge | [IR] | SG3/SG4 sets are 30° apart; bar arc-width + electrode-set width must stay under 30° with guard band. |
| C9 | Momentary-bridge transfer is partial | [RH] | Per-event charge is arc-duration-limited; a sweet spot exists between transfer and back-conduction. |

## 9. Modelling status

- **Ceiling [OC]:** ideal-diode per-cycle gain `z = 1.203` at the device point (solver,
  unchanged). The spark commutator gives `z_spark < z`.
- **Startup threshold [RH]:** no firing until |V_source − V_sink| ≥ V_strike; the strike
  penalty fades as V grows (`z_spark → z` for V ≫ V_strike). Implies a minimum seed voltage.
- **Open — spark-transfer model [RH]:** per-event charge as f(strike voltage, arc-duration
  /quench window, node capacitances, 6-bar throughput), run to asymptote against the `z`
  ceiling, locating the arc-duration sweet spot. Inputs fully specified by §§3–7.
- **Producer/consumer:** `solveDoubler4` (ideal diode) is the canonical anchor and is never
  edited by this work. A spark-transfer model, if built, is a separate consumer; if it ever
  graduates into `index.html` it gets its own brief.

## 10. Superseded approaches

- **Triggered trigatron** — rejected: too complex; too many unmeasurable, drifting variables;
  temperature drift corrupts a *timed* instant.
- **Diodes / solid-state controlled switches** — rejected: reverse "back-pressure" needs
  exotic/military-spec parts; controlled switches need isolated gate drive on a free-spinning,
  slip-ring-free frame.

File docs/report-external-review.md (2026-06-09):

# External Review Report — Rotary-Varicap Bennet-Doubler Design Calculator

**Artifact under review:** `index.html` — a single, self-contained web page (no build, no server, no dependencies, no network, no `localStorage`).
**Build stamp:** `C-I v0.2 · T v0.1 · flow+presets v0.2 · xsec v0.2.2 · S v0.1 · commutator v0.1` (shown in the page header).
**Reviewed against:** commit `800d87f` (2026-06-08). Every numeric anchor in this report was re-verified by a headless run of the page's own self-test battery and producer functions on this commit.
**Companion document:** `docs/report-tool-functioning.md` — a deeper functional walk-through of the host solver and Blocks C-I/M. This report is the authoritative, current overview: it covers all blocks (host, C-I, M, R, D, T, design-flow, S, and the commutator render) and supersedes the companion's block coverage where they differ.
**Purpose:** give an external reviewer everything needed to judge the tool's correctness, scope, and honesty — what it claims, how each claim is validated, what was deliberately corrected, and what is explicitly out of scope.

---

## 0. Provenance firewall (read first)

The **working methodology** — epistemic tier tags, a `CHANGELOG.md` audit trail, symbol-hygiene rules, and producer/consumer discipline — is adapted from the "DCCREG programme conventions."

**The physics and mathematics are entirely mainstream.** Specifically: parallel-plate capacitance, a rotary variable capacitor, the cross-coupled Bennet charge doubler, standard solid-mechanics geometry, the Smith–Weintraub air-refractivity relation, the Buck (1981) saturation-vapour-pressure correlation, DIN 6885 parallel-key sizing, circular-loop self/mutual inductance via complete elliptic integrals (AGM), the skin effect, LC resonance, series-resonant DC-block coupling, and the salient-pole reluctance-torque relation `T = ½·i²·dL/dθ`. **No proprietary or unconventional theory is used or required.** Every substantive claim in code and docs carries a tier tag so a reader can separate standard results from modelling choices:

- **[OC] Operational Core** — standard derivable physics/math; true independent of this project.
- **[IR] Interpretive Reading** — a modelling / engineering choice; internally consistent, chosen.
- **[RH] Resonance / Heuristic** — suggestive framing, not load-bearing.

---

## 1. What the tool is

An interactive design calculator for one electromechanical device: a **rotary variable capacitor that drives a symmetric 4-node Bennet voltage doubler**, with the surrounding mechanical core, central resonator, reluctance spin-up motor, and built-in transfer capacitors all modelled in the same page. It connects layers normally treated separately, so a designer moves from *physical dimensions* to a *predicted electrical pumping ratio* plus mechanical, resonant, motor, transfer-cap, and firing-sequence characterisations in a single view, with a cascade that derives the dependent parameters from a handful of primaries.

It is an **exploration / sizing tool** — **not** a manufacturing release and **not** a hardware-validated simulator. It answers: "for this geometry, gap, dielectric, and a few electrical inputs, does the doubler pump (z > 1), how strongly, with what margin — and is the implied machine physically coherent?"

---

## 2. Architecture and the central safety property

- **Single global `state`** holds every parameter. The 59 numeric inputs are declared once in a `FIELDS` table (`id, default, min, max, step`) and auto-wired to a paired range slider + number box; non-numeric controls (enums, checkboxes) are handled explicitly.
- **Reproducibility:** the complete parameter set serialises into the URL hash on every change ("copy share-url"); opening that URL reproduces the exact state. No server, no database, no storage.
- **Producer / consumer discipline (the load-bearing invariant).** The electrical engine `solveDoubler4(...)` is the **consumer** and is **never edited by feature work**. Every other block is a **producer** that computes geometry/physics and, at most, writes the solver's *input* state at a single call site:

| Block | Role | Touches the solver? |
|---|---|---|
| Host `solveDoubler4` | switched-capacitor network solver → pumping ratio `z` | — (consumer, frozen) |
| **C-I** plate geometry | geometry + gap + dielectric → rotor `Cmin/Cmax` | drives rotor caps (pre-step) |
| **M** mechanical core | quadricone / shaft / void / disc, DIN keys, HV clearances, guards | no — readouts + cross-section |
| **R** central resonator | conical-coil `L ∥ C_R` tank, f₀/Q/ringdown | no — readouts + cross-section |
| **D** distributed-EM motor | 12-C-EM reluctance spin-up, Q/turns/voltage budget | no — readouts + top-view |
| **T** transfer caps | bus-ring Ca/Cb geometry → capacitance | optional `tcDrive` writes `ca`/`cb` at call site |
| **Design-flow + presets** | one-pass cascade of primaries → slaved inputs; JSON preset load/save | only via the documented `tcFromCmax`/`tcDrive` call-site wiring |
| **S** firing sequence | read-only `traceDoubler4` trace → 4 firing/clocking panels | no — pure sink, never writes solver state |
| **Commutator** render | physical realisation of D1–D4: axial companion + front-view overlay | no — render/consumer, reads geometry only |

A reviewer can verify the invariant directly: the five frozen primitives (`solveLinear`, `chargesFromVoltages`, `solvePhase`, `solveDoubler4`, `zSym`) are **byte-identical** across every feature commit (verified by per-function md5). All feature work is upstream of them.

- **Self-test gate.** The page runs a fixed battery of deterministic checks **on load**; the "engine verified" badge turns green only if **all** pass, and an expandable table shows every row (§5).
- **Render layer.** All canvases use a shared 2D idiom (`clearCanvas` → measured `{ctx,w,h}`), so panels reflow to their container. The four Block-S panels and the Block-M cross-section are full-width; the polar clocking map gets its own enlarged full-width canvas. Drawing is read-only and never feeds back into state.

---

## 3. Block-by-block technical summary (with validated anchors)

All anchors below are the values produced by this commit (default cascaded state unless noted), confirmed in the headless run.

### Host — symmetric 4-node Bennet doubler `[OC]`
Cross-coupled regenerative topology (C1:1↔0, C2:4↔0 variable; Ca:1↔2, Cb:3↔4 fixed; Cpar per node; diodes D1 2→0, D2 3→0, D3 1→3, D4 4→2). Each phase brute-searches all 16 diode on/off states, keeps those consistent with the off-diode bias constraints, takes the one maximising |V₁|+|V₄|, iterates two-phase cycles, and returns the median asymptotic per-cycle ratio `z`. **Anchors:** no-swing → z = 1.000; device (160–1000 pF) → z = 1.203; wide (100–2000) → z = 1.438; narrow (400–600) → z = 1.000; C1↔C2 swap symmetric.

### Block C-I — plate geometry → rotor capacitance (v0.2) `[OC] / [IR]`
A sectored disc (alternating kept sectors) + an optional conductive central ring set a finite `Cmin` floor; dielectric is vacuum, **live moist air** (Smith–Weintraub + Buck), or fixed-nominal mica/Kapton; `C = ε₀·εᵣ·A/g`.
**v0.2 active-overlap correction.** The swinging rotor↔stator overlap is **not** the full rotor face: the counter-rotating stator cannot reach the central HV tank (inner void `pvoid`) nor overlap the 6 rim steel cores (outer quad band `pquadfoot + pquadclr`). `plateGeom` now returns **two** areas — `Ametal_full` (full face) and `Ametal_active` (band `[ro+pvoid, plateR−pbus−(pquadfoot+pquadclr)]`). **The pump (C1/C2) uses the squeezed active area; the resonator C_R uses the full face — they are decoupled.** **Anchors (defaults):** `A_active = 0.2211 m²`, `A_full = 0.3839 m²` (squeeze 0.576), active band 95…387 mm; `Cmax = 4.20 nF`, `Cmin = 278 pF` (ring on); dry-air εᵣ(0 °C, 1013 hPa, 0 %) = 1.000576.

### Block M — rotor mechanical core `[OC] / [IR]`
A 45° "quadricone" pair + stub shafts + spherical void + dielectric disc/septum. The hub comes from DIN 6885 key sizing, or from the C-I ring when coupled; spherical-cap/belt/bore volumes; four hard feasibility guards (collar / void-seat / wall / key-fit) + a keyway-collar soft guard; HV clearance/creepage geometry; and a live, dimensioned, scale meridional cross-section. **Anchors:** hubDia(void 50, shaft 35, discH 0) = 197 mm; void partition 2·cap + belt = sphere; `keyLenFor(35)` → DIN 56; default coupled coneR 75 mm, hub ⌀ 150 mm, disc ⌀ 1000 mm. Working unit is **mm** (correction C2).

### Block R — central resonator `[OC]`
A `C_R ∥ L` tank: two conical coils (series, aiding) wound on the quadricones, and the through-mica inter-electrode capacitor. Inductance via an exact conical loop-stack — HF self-inductance + Maxwell mutual over all turn pairs, with complete elliptic integrals by the AGM (no library), decimated to ≤400 nodes for fine wire (flagged). Plus a Medhurst self-capacitance estimate and coil self-resonance; `f₀, f_d, Z₀`, a **copper-only (upper-bound) Q**, ringdown τ, skin δ; RPM-driven PRF and the ringdown-vs-build-up regime. **Anchors:** `ellipKE(0)` → K = E = π/2; capillary `C_R = 1.91 nF`; validated loop-stack `L ≈ 131 µH` (capillary self-test config); default coupled tank `L = 123 µH, f₀ = 326 kHz`; tube OD3/ID1 ≡ rod OD3 at HF; `awgToCond(20)` = 0.812 mm; PRF(N12, 3000 rpm) = 300 Hz. (The brief's `f₀ ≈ 238 kHz` was a cruder cylindrical estimate — see correction C3.)

### Block D — distributed-electromagnet spin-up motor `[OC] / [IR]`
12 stator C-electromagnets in two interleaved groups of 6 (odd → group A on transfer cap C3, even → group B on C4), uniform winding; the N-S-N-S ring pattern is a *consequence* of the two transfer caps swinging antiphase (push-pull). A series resonant DC-block cap blocks the kV bias, passes the low-frequency stepping drive at minimum impedance, and stays a high-Z spectator at f₀. The Q/turns/voltage budget yields the **closed-form, frequency- and turns-independent ampere-turn limit** `N·I = (V_rating − V_bias)·√(C·l_gap/(μ₀·A))`. A top-view projection shows the sectored disc, the 6 rotor poles, and the 12 C-EMs with polarity. **Anchors (worked design point, bias 12 kV / rating 20 kV — the self-test point):** PRF 300 Hz; alt-stroke L = 2.56 H, Z₀ = 2411 Ω, N ≈ 3190, **N·I ≈ 10 585 A-t** — identical at per-stroke drive (300 Hz, N ≈ 1595); energy ½·440 nF·(20 kV)² = 88 J/coil; per-group cap = 6·C = 2.64 µF. With the **default cascade** (`vhvKV = 20`, rating 30, headroom 10 kV) the on-load value is **N·I ≈ 13 230 A-t**.

### Block T — built-in transfer caps Ca/Cb (v0.1) `[OC] / [IR]`
A **solid annular bus ring** (full area, **no keptFrac**) buses the otherwise-unconnected stator sectors *and* serves as the lower Ca/Cb plate; Mylar + an upper electrode complete the cap (Ca on the top face, Cb on the bottom). It consumes C-I's `rActiveInner/rActiveOuter`. Inverse (Ca → width) and forward (width → Ca) modes; inside placement default (inner edge pinned, grows outward, ≤ `rActiveOuter`), outside toggle. Reports band-max Ca, dielectric field, and ½·C·V² energy. The copper–Mylar–copper stack renders on the back of each stator plate in the M cross-section, lifted on a tunable axial bracket. **Anchors (1 mm Mylar, εᵣ 3.2, inside):** Ca 4/7/11 nF → 129/191/258 mm width; band-max 12.3 nF; field 20 kV / 1 mm = 20 kV/mm; energy 7 nF · 20 kV = 1.4 J; round-trip exact. With the default `tcFromCmax` link on, Ca = Cb = 1.5·Cmax ≈ 6.29 nF (width ≈ 178 mm).

### Design-flow inheritance + parameter-set presets `[OC] / [IR]`
Five default-on, overridable couplings cascade the design primaries to the slaved inputs in one acyclic pass (`cascadeState`) before any producer runs: `vhvLink` (HV void = `vhvKV/vhvEkVmm`, Block-T design V, motor bias ← `vhvKV`), `quadLink` (`pquadfoot = 2·demQuadConeRmm`), `demRpmLink` (motor RPM ← master `rrpm`), `demEvLink` (`demEventsPerRev = ⌈pnsec/2⌉`, making the R and D PRF identical by construction), and `tcFromCmax` (`Ca = Cb = tcRatio·Cmax`, driving the solver). Presets are JSON of **primaries + toggles + an `expect` block**; "Load parameter set" reads a self-documenting file (`FileReader`), validates (unknown/out-of-range keys warned and skipped — never applied silently), applies, runs the cascade, **checks each `expect` within tolerance**, updates the hash, and shows a notes panel; "Save current as preset" exports a scaffold. **No magnitude is hard-coded in prose** — `presetExpectGetters` defines the checkable outputs and the preset asserts them. The shipped **R1 baseline** (`presets/R1-baseline.json`) verifies on load: CmaxNF 4.19, CaNF 6.29, prfHz 300, pvoidMm 20, f0kHz 326 — all within tolerance.

### Block S — firing sequence & clocking (read-only sink) `[OC] / [IR] / [RH]`
`traceDoubler4` is a read-only **sibling** of `solveDoubler4` — the identical loop, recording the per-phase node-voltage trace and reusing the frozen `chargesFromVoltages`/`solvePhase`; it carries the running rescale so the consumer reconstructs `Vtrue = V/scale`. A self-test asserts `traceDoubler4.z ≡ solveDoubler4.z` (z = 1.2033 at the device point) within 1e-9. Four full-width canvas panels: `seq-v` (gap voltages with the convex 1/C within-stroke rise, peaks growing ×z/cycle), `seq-logic` (SG3/SG2/SG4/SG1 conduction with stroke bands), `seq-tank` (impulse-kicked damped 5–6 ring whose envelope grows with the pump, plus a resolved-carrier inset), and `seq-clock` (an enlarged polar map: `groups = ⌈Nsec/2⌉`, `pitch = 720/Nsec°`, reacting to geometry `pnsec`). A single timing source `machinePRF() = ⌈pnsec/2⌉·rrpm/60` feeds every panel; a self-test asserts it equals `resonatorCore.prf` and `demMotor.prf`. The tank carrier/decay default to the live Block-R `f₀`/`Q` (`sf0`/`sq0` = 0 ⇒ auto), so no f₀ figure is hard-coded. **[RH]** Caption discipline: only the 5–6 curve is bench-measurable (nodes 1–4 sit on the free counter-rotating stator); the rest is design guidance. The conduction-window/follower-lag angles are display placeholders (open forks F-S1/F-S4).

### Commutator render `[IR]`
A render/consumer visualisation of the frozen switching design in `docs/commutator-design.md` (the physical realisation of diodes `D1–D4` as a rotary, mechanically-timed electrostatic commutator). Two coordinated views: an **axial companion** (new face-on panel — rotor disc + `Nsec` sectors, 6 floating bars at the transfer radius with ball ends, the SG3/SG4 stator sets with the **30° offset drawn**, firing windows + favourable-half shading, a live `kphi` rotor-angle slider) and **front-view overlay** additions in the cross-section (mirrored top/bottom bar sets, stator electrodes across two series spark-gaps per bar, cross-ecliptic sink routing). A `drawLegend` helper encodes **colour = electrical frame** (rotor / stator / **floating bars** / rail) and **hatch = material**; the floating bars get their own colour — the key distinction. Pure `commutatorGeom(state)`: bar count `⌈Nsec/2⌉`, the 30° offset resident in the stator sets with the bar sets axially aligned, transfer-circle radius `ktransrad` (outboard of `rActiveOuter`). Render-only — `k*` inputs have no solver coupling; the spark-transfer `z_spark` model is left open per the design doc §9.

---

## 4. Corrections made openly (reviewer attention)

Per the "correct openly" convention each of these is recorded in `CHANGELOG.md` with its reason. They are the points where the implementation **departs from, or corrects, a brief** and therefore most warrant review.

- **C1 — C-I sectored area.** Original code used the full disc; corrected to the annulus *outside* the ring (the inner disc is the hub/ring, not free sectors), removing a ~2 % overcount. `[review finding]`
- **C2 — Block M working unit.** Briefs specified cm/in; the implementation uses **mm** as the realistic base for these component sizes (void 50, disc 1000). `[IR, recorded]`
- **C3 — Block R inductance / f₀.** The brief quoted `L ≈ 235 µH / f₀ ≈ 238 kHz` from a cruder cylindrical estimate; the validated conical loop-stack (cross-checked against Nagaoka) gives `L ≈ 131 µH` for the capillary self-test config and `f₀ ≈ 326 kHz` at the R1 baseline. The validated values are used and self-tested/asserted; the stale figure was retired entirely by moving the magnitude into the R1 preset's `expect`. `[corrected openly]`
- **C4 — C-I ↔ M coupling.** A user-directed hard link (plate ⌀ → disc ⌀, ring-out ⌀ → hub ⌀) supersedes the briefs' warn-only stance; the DIN key assembly becomes a boundary condition with a new hard guard. `[IR, user-directed]`
- **C5 — C-I v0.2 active-band guard.** The instruction's area formula `max(0, rOut² − rIn²)` is insufficient: once `rActiveOuter` goes **negative** its square exceeds `rActiveInner²` and reports a *spurious* pumping area. Replaced with a band-**width** guard (`rActiveOuter > rActiveInner`). **This bug was caught by the v0.2 collapse self-test** — evidence the battery is doing its job. `[OC correction of instruction]`
- **C6 — Block D top-view.** A user-directed axial top-view projection (sectors + 6 rotor poles + 12 C-EMs in one plane) supersedes the brief's §8 side-view ring. `[IR, user-directed]`
- **C7 — `demCapRatingKV` default 20 → 30 kV.** With the design-flow `vhvLink` on, `demBiasKV ← vhvKV = 20`; leaving the rating at 20 would give zero AC headroom and a spurious "no torque / over-voltage" Block-D warning on first load. Raising the (free) rating default to 30 lands the default cascade coherently (10 kV headroom). `[IR, recorded]`
- **C8 — `tcBracketMm` repurposed (radial → axial); radial pin renamed `tcInnerPinMm`.** The cross-section render brief defines `tcBracketMm` as the **axial** Ca/Cb standoff, but Block-T v0.1 already used that id for the **radial** inner-pin clearance. The radial input was renamed to `tcInnerPinMm` (unchanged 15 mm default/behaviour) to free `tcBracketMm` for the brief's axial meaning, honouring its explicit "do not conflate" instruction. `[IR, recorded]`
- **C9 — Cross-section motor geometry (xsec v0.2.2).** The §5e rotor pole was sized from a free radius and overflowed the rim band ("ate the rotor"); it is now a band-sized square derived from `[rActiveOuter, rRotorOuter]`, the C-EM winding moved to the vertical spine, and the two ±x C-EMs made exact mirrors. Factored into a pure helper (`cemMotorGeom`) so the six new geometry self-tests run without a DOM. `[IR render]`

---

## 5. Verification status

**All 66 deterministic self-tests pass** on commit `7796b72` (engine badge: *verified*). The battery is the regression gate: any change that breaks a modelled relationship flips the badge red on load. The tests are pure functions of the producer code (no DOM), so they reproduce headlessly.

| Group | Count | Coverage |
|---|---|---|
| Host solver | 5 | no-swing, device, narrow, wide, C1↔C2 swap symmetry |
| Block C-I | 8 | dry-air εᵣ, fixed-geom Cmax; v0.2: A_active, A_full, band radii, **C_R invariance under squeeze**, pump ∝ active area, collapse guard |
| Block M | 3 | hubDia, void-partition identity, DIN key length |
| Block R | 6 | AGM elliptic, C_R, validated L, tube ≡ rod HF identity, AWG OD, PRF |
| Block D | 7 | resonance round-trip, Z₀ identity, **N·I invariance**, over-V flag, 88 J energy, N-S-N-S parity, per-group cap |
| Block T | 7 | inverse widths, round-trip, band-max + overrun, Ca = Cb, field, inside > outside, energy |
| Design-flow + presets | 8 | export→load round-trip, partial load, **R1 expect-pass**, corrupt-expect-surfaces-✗, inheritance-overwrite warn, unknown-key warn, bad-JSON safety, flow identities + idempotent cascade |
| Cross-section render | 11 | bracket px→mm, pole-in-band, motor gap from Block D, rim-clamp straddle, legend coverage; **v0.2.2:** C-EM mirror symmetry, no-inboard-overrun, spine-clears-disc, pole-fills-band, two-equal-axial-gaps, coil-on-spine |
| Block S firing sequence | 5 | **tracer ≡ frozen solver**, SG3-peak growth ≈ z, tank kicks monotone, clocking groups/pitch, **PRF single-source ≡ R ≡ D** |
| Commutator render | 4 | SG3↔SG4 offset = sector pitch, bar sets axially aligned, no cross-bridge, transfer radius outboard |

The standout rows are the **invariance / decoupling** guards — they prove a *relationship*, not just a point value: C-I "C_R invariant under squeeze" (the squeeze never reaches the resonator), D "N·I invariance" (the ampere-turn limit is genuinely frequency-independent, not an accident of one operating point), S "tracer ≡ frozen solver" and "PRF single-source ≡ R ≡ D" (the visualiser and the timing sources cannot drift from the engine).

**Verification method.** In-browser self-test on load, plus headless re-runs of `runSelfTest()` and the producer functions under Node with a stubbed DOM (the source of every anchor in this report). **Reviewer to-do:** open the page once to confirm the canvases render without console errors — the numeric engine is independently verified, but the *drawings* (cross-section motor clamp, top-view, the four Block-S panels) are best confirmed visually.

---

## 6. Scope boundaries — what the tool does NOT assert

Deliberately out of scope (deferred; **not** modelled, **not** claimed):

- **Dielectric breakdown / safe-voltage limits** across any gap. HV *geometry* (clearance, creepage, dielectric field) is reported; a pass/fail safe-voltage verdict is not. Block D raises a derated HV-void warning (1 kV/mm) and Block T a field warning (>40 / >100 kV/mm) as **flags, not guarantees**.
- **Conduction / leakage / loss** in the pump; **fringing-field** corrections (a heuristic warning fires when the gap exceeds ~10 % of the smallest in-plane feature, but C is the ideal parallel-plate value).
- **Rotational inertia, mass, balance, bearings, seats** (mechanical detail); **leg-height / bracket structural design** in Block T (only the radial placement, the axial standoff, and the Mylar thickness are real there — the rest is render-schematic).
- **Mica tanδ and spark-gap loss** in Block R (Q is a copper-only *upper bound*; the real loaded Q is far lower).
- **Torque vs. stator drag / inertia** in Block D (ampere-turns feed a future torque estimate once rotor-pole geometry is fixed).
- **The Block-S forks:** SG breakdown clamp / saturation (F-S1), real series-LC tank coupling (F-S2), absolute kV from the operating point (F-S3, the y-axes stay normalised), and conduction-window / follower-lag **angles** from a switch-timing sim (F-S4). The Block-S firing/clocking panels are presentational design guidance, not a timing simulation.

---

## 7. Open questions a reviewer may want to challenge

1. **Drive-frequency mapping (Block D).** Alt-stroke (PRF/2) vs per-stroke (PRF) changes the coil L (hence N) by 4×; the ampere-turn limit is invariant but the *winding* is not. The mapping must be confirmed against the actual stroke→cap pattern before winding.
2. **Transfer-cap scale wiring (Block T → solver).** Block T produces nF-scale Ca/Cb; the host's manual `ca/cb` range was pF-scale (≤ 500). The `tcDrive`/`tcFromCmax` hand-off raises the field max to admit nF values rather than silently clamping. Confirm nF-scale transfer caps are intended for the *physical* (plate-driven, thousands-of-pF) regime, not the abstract demo presets.
3. **Decoupling premise (C-I v0.2).** C_R keeps the full rotor face on the assumption the stator clearances are purely a *stator* concern and the rotor↔rotor through-mica path is unaffected. This is the hinge of the squeeze/decoupling split.
4. **Reluctance-rotor polarity premise (Block D).** The N-S-N-S map and the torque rest on the two transfer caps being genuinely antiphase (push-pull). The tool asserts the parity but cannot prove the antiphase drive — that is a system-level claim.
5. **Resonator alignment premise (Block R).** A real through-mica C_R assumes the rotor electrodes fully align (antiphase supplied by the stator offset). Partial alignment shifts C_R and f₀.
6. **Default operating-point coherence.** The default cascade (vhvKV 20, rating 30, Ca = 1.5·Cmax) was tuned so all guards land green on load; confirm it represents an intended design point, not just a green-light convenience.

---

## 8. How to reproduce / review

1. **Run it:** open `index.html` in any modern browser (offline is fine). Confirm the header badge reads **"engine verified"** and the self-test table (under *Topology & diode schedule*) shows all 66 rows passing.
2. **Inspect the invariant:** confirm the five frozen primitives are unchanged from the validated host engine; all blocks are upstream producers. (`git log -p` on `index.html` filtered to those functions shows no edits.)
3. **Re-run the battery headlessly:** extract the `<script>` body, stub a minimal DOM, call `runSelfTest()`, assert `.ok === true` and `rows + plateRows` count = 66. This is how every anchor in this report was produced.
4. **Load the R1 preset:** "Load parameter set" → `presets/R1-baseline.json`; confirm the five `expect` chips report ✓ within tolerance.
5. **Probe the corrections (§4) and the open questions (§7)** — those are where judgment, not arithmetic, is required.
6. **Share state:** "copy share-url" captures any configuration; the URL hash is the full, reproducible parameter set.

---

## 9. Provenance and reference inputs

- **In-repo briefs (authoritative for their internals):** `docs/brief-blockC1-geometry-to-rotorcap.md`, `…blockM…`, `…blockR…`, `…blockD…`, `…blockS…`, `docs/commutator-design.md` (the frozen switching design — physical realisation of D1–D4), and the system context `docs/doc-circuit-topology-resonances-materials.md`. The Block-T, design-flow, and cross-section briefs were external working documents; their content and every deviation are recorded in `CHANGELOG.md`.
- **Conventions and audit trail:** `CONVENTIONS.md` (tier tags, symbol hygiene, block namespaces, the producer/consumer rule) and `CHANGELOG.md` (every change with its reason).
- **Reference prototypes (committed, not served):** `reference/SectoredDiscCalculator.jsx` (C-I area math) and the Block-S Python mirror/plot prototypes `reference/doubler_core.py`, `reference/sg_sequence_from_solver.py`, `reference/clocking_map.py`.
- **Shipped preset:** `presets/R1-baseline.json` (the worked baseline; the only place its magnitudes live, asserted via `expect`).
- **Companion:** `docs/report-tool-functioning.md` (functional walk-through).

*All physics mainstream; all modelling choices tier-tagged; all corrections logged. The tool is a verified sizing / exploration calculator, not a hardware-validated simulator.*

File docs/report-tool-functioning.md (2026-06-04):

# Functional Report — Variable-Capacitor → Symmetric Bennet Doubler Design Tool

**Artifact:** `index.html` (single self-contained web page; no build, no server, no dependencies)
**Scope of this report:** how the tool works — its purpose, models, data flow, interface, verification, and limitations.
**Status:** working and self-tested. Host doubler + Block C-I (plate capacitance) + Block M (rotor mechanical core), with geometric coupling between the two geometry blocks.

> **Provenance / firewall.** The *working methodology* (epistemic tier tags, a changelog audit trail, symbol-hygiene rules, producer/consumer discipline) is adapted from the "DCCREG programme conventions." **The physics and mathematics in the tool are entirely mainstream** — parallel-plate capacitance, a rotary variable capacitor, the Bennet charge doubler, standard solid-mechanics geometry, the Smith–Weintraub air-refractivity relation, the Buck (1981) vapour-pressure correlation, and DIN 6885 key sizing. **No proprietary or unconventional theory is used or required.** Every substantive claim carries a tier tag (below) so a reader can separate standard results from modelling choices.

---

## 1. Executive summary

The tool is an interactive design calculator for a specific electromechanical device: a **rotary variable capacitor that drives a symmetric 4-node Bennet voltage doubler**. It links four layers that are normally treated separately:

1. **Electrical engine (host).** A switched-capacitor network solver that computes the asymptotic per-cycle voltage-gain ratio **z** of a cross-coupled 4-node Bennet doubler from the capacitor values.
2. **Electrical front end (Block C-I).** A parametric model of the rotor capacitor plate (sectored disc + central ring) that converts *geometry + gap + dielectric* into the rotor capacitance extremes **Cmin / Cmax**. These now **drive the rotor capacitors of the doubler automatically**.
3. **Mechanical core (Block M).** A parametric model of the rotor's structural body (a 45° "quadricone" pair, stub shafts, a central spherical void, and a dielectric disc/septum), with industry key sizing, feasibility guards, high-voltage clearance/creepage geometry, and a live scale cross-section drawing — also showing the fixed stator plates.
4. **Central resonator (Block R).** A parametric model of the `C_R ∥ L` resonant tank formed by two conical coils (wound on the quadricones, in series) and the through-mica inter-electrode capacitor — giving the resonant frequency, impedance, copper-limited Q, ringdown, and the RPM-driven pulse-train regime. It draws the coil onto the same cross-section.

The geometry blocks are **coupled**: the capacitor plate diameter sets the structural disc diameter, and the capacitor ring's outer diameter sets the mechanical hub/cone diameter (which in turn fixes the resonator coil's geometry). The single page therefore takes a designer from *physical dimensions* to a *predicted electrical pumping ratio*, a *mechanically-checked, dimensioned cross-section*, and a *resonant-tank characterisation* in one view.

The page **self-tests on load**; an "engine verified" badge and an expandable table report a fixed set of deterministic checks. All checks currently pass.

---

## 2. Purpose and intended use

- **Primary question answered:** "For a given rotor-plate geometry, gap, dielectric, and a few stray/transfer capacitances, does the Bennet doubler pump (z > 1), how strongly, and how much margin is there — and is the implied mechanical core physically realisable?"
- **Audience:** a designer exploring the parameter space of this device. It is an **exploration / sizing tool**, not a manufacturing release or a hardware-validated simulator.
- **Out of scope (by design, see §11):** dielectric breakdown / safe-voltage limits, conduction and leakage losses, fringing-field corrections, rotational inertia / mass / balance, and bearing/seat detail. These are deferred to later work and are explicitly *not* asserted by the tool.

---

## 3. System architecture

- **Single file.** Everything (markup, CSS dark theme, and all JavaScript) lives in one `index.html`. It runs offline in any modern browser. There is **no build step, no network call, and no `localStorage`**.
- **State.** A single global `state` object holds every parameter. Numeric inputs are declared once in a `FIELDS` table (`id, default, min, max, step`) and auto-wired to a paired range slider + number box. Non-numeric controls (dielectric choice, toggles) are handled explicitly.
- **Shareable URL.** The complete parameter set is serialised into the page's URL hash on every change ("copy share-url"). Opening that URL reproduces the exact state — this is the reproducibility mechanism (no server, no database).
- **Producer / consumer discipline.** The electrical solver `solveDoubler4(...)` is the *consumer* and is never edited by feature work. The geometry blocks are *producers*:
  - **Block C-I** produces the four rotor-capacitance values consumed by the solver.
  - **Block M** is an **independent producer** of mechanical readouts and a drawing; it never writes electrical state and never calls the solver.
  This separation keeps the validated electrical engine isolated from front-end changes.
- **Recompute loop.** Any input change schedules a single debounced `recompute()` that (a) runs the Block C-I pre-step (geometry → rotor caps), (b) runs the Block M readouts + cross-section, (c) runs the doubler solver and updates all outputs and charts.

---

## 4. The device (physical picture)

A central **dielectric disc** carries a sectored capacitor **electrode on each face** (the two rotors, "C1" on top and "C2" on the bottom), mirrored across the disc mid-plane. Each electrode is a sectored annulus whose inner edge sits at the hub and whose outer edge is the plate/disc rim. A **fixed stator plate** faces each rotor electrode across a small **gap g** — this electrode↔stator gap is the working capacitor gap. As the rotor turns, the overlap between the sectored rotor electrode and the stator sweeps the capacitance between **Cmin** and **Cmax**.

Structurally, a **45° quadricone half** is bonded to each electrode (base at the hub, tapering outward to an apex), and a **stub shaft** (one per side — never a through-shaft, which would short the two rotors together) couples each apex to a bearing/drive. A **spherical void** at the assembly centre keeps the two electrodes apart; the disc fills the void's equatorial belt as a solid dielectric **septum** with a small central **bore**. Two sectored groups offset by one sector pitch realise the doubler's two **antiphase** rotors: when C1 is at Cmax, C2 is at Cmin.

This is the device the three computational blocks describe.

---

## 5. Electrical engine — symmetric 4-node Bennet doubler (host) **[OC]**

**Topology.** Four nodes above ground:
- Variable rotor capacitors: **C1** (node 1↔gnd) and **C2** (node 4↔gnd).
- Fixed transfer capacitors: **Ca** (1↔2) and **Cb** (3↔4).
- Stray capacitance **Cpar** from each node to ground.
- Four ideal diodes: D1 (2→0), D2 (3→0), D3 (1→3), D4 (4→2). The cross-diodes D3/D4 are the regenerative cross-couple that lets the 4-node device pump without relying on parasitic asymmetry.

**Solver method.** The engine runs the device as a two-phase-per-cycle switched-capacitor network:
1. Each phase conserves the per-node charge from the previous phase.
2. It brute-force searches all 16 diode on/off combinations; a combination is *consistent* if every "off" diode is reverse-biased (V_from ≤ V_to) and on-diodes short their endpoints. Each candidate is solved as a small linear system (Gaussian elimination over the conducting clusters).
3. Among consistent states it keeps the one maximising |V₁| + |V₄|.
4. It iterates 120 cycles, discards a burn-in, and returns the **median asymptotic ratio z = (|V₁|+|V₄|)ₙ / (|V₁|+|V₄|)ₙ₋₁**, rescaling to keep magnitudes bounded.

**Outputs derived from z:** growth ×/cycle, % per cycle, cycles-to-×10 and ×1000, a live C1↔C2 swap-symmetry check, and a **transfer-cap headroom** analysis (it sweeps Ca = Cb to find the z = 1 critical point and reports remaining margin or deficit). Two canvas charts plot z versus the rotor swing ratio and z versus Ca = Cb.

**Interpretation of z:** z > 1 = "PUMPING", z ≈ 1 = "KNIFE-EDGE", z < 1 = "STALLED".

---

## 6. Block C-I — plate geometry → rotor capacitance (electrical front end)

Converts the rotor-plate geometry into the capacitance extremes that drive the solver.

### 6.1 Capacitance model **[OC]**
Parallel-plate law in SI, scaled to picofarads:

```
C = ε0 · εr · A_overlap / g ,     ε0 = 8.8541878128×10⁻¹² F/m
```

The plate is a disc of `Nsec` equal sectors with alternating sectors kept as conductor (kept fraction = ⌈Nsec/2⌉ / Nsec — e.g. **12 sectors → 6 kept / 6 gaps**, 8 → 4/4), plus a central conductive ring (annulus). Rotation makes the sector overlap a triangular function of angle, so:

```
C_max = ε0·εr·(A_metal + χ_ring·A_ring) / g        (full sector overlap)
C_min = ε0·εr·(χ_ring·A_ring) / g                   (sectors over gaps)
swing ratio κ_C = C_max / C_min                      (= the host's r₁/r₂)
```

The ring is azimuthally symmetric, so it contributes a **rotation-independent capacitance floor** — it is the knob that keeps Cmin (and therefore the swing ratio) finite and tunable. Turning the ring off sends Cmin → 0 and κ_C → ∞ (flagged with a warning).

### 6.2 Dielectric model (→ εr)
| Dielectric | εr | Model |
|:--|:--|:--|
| Vacuum | 1 (exact) | constant **[OC]** |
| Air | ≈ 1.0006 | live function of T, pressure, humidity **[OC]** |
| Kapton | 3.4 (band 3.0–3.5) | fixed nominal **[IR]** |
| Mica | 5.4 (band 5.0–7.0) | fixed nominal **[IR]** |

The **moist-air** model is live (shown only when "Air" is selected):

```
εr_air = 1 + 2·N_air×10⁻⁶
N_air  = 77.6·P/T + 3.73×10⁵·p_v/T²          (Smith–Weintraub, N-units)
p_v    = (RH/100)·p_sat
p_sat  = 6.1121·exp[(18.678 − T_C/234.5)·T_C/(257.14 + T_C)]   (Buck 1981), hPa
```

with T in kelvin and pressures in hectopascals. (Honest note: air differs from vacuum by < 0.1 %; the model is included for completeness and correctness, not because the effect is large.)

A practicality note is surfaced when a **solid** dielectric is chosen, because a bonded film cannot in practice be rotated against both plates of a rotary capacitor — mica/Kapton are offered as fixed-gap "what-if" exploration. **[IR]**

### 6.3 Driving the solver (inheritance)
By default the rotor source is **"plate"**: the computed **Cmin/Cmax drive all four rotor fields** (C1 and C2 share the plate geometry — the symmetric design — linked by default). Those four inputs are then **read-only/disabled** and the panel is labelled "inherited from plate geometry." Only **transfer + stray (Ca, Cb, Cpar) remain user inputs**, because they cannot yet be estimated from geometry. A manual-override toggle remains for direct solver exploration. In plate mode the rotor-field maximum is raised to 10000 pF (realistic plate capacitances can exceed the manual 3000 pF range); values beyond that clamp with a visible warning.

---

## 7. Block M — rotor mechanical core

Models the structural body the electrode rides on. **It never feeds the solver** — it produces readouts, feasibility guards, and the cross-section.

### 7.1 Geometry **[OC]**
A 45° half-angle cone has height = base radius, so for cone base radius `R_c`:

```
quadricone volume   = (2/3)·π·R_c³                 (both cones)
cone cap depth      = voidR − discH/2              (spherical cap per cone)
insertion depth     = R_c + discH/2 − voidR        (bore must clear the void pole)
keyed length avail. = insertion depth − shaftR
```

The void is a sphere centred on the disc mid-plane; each cone holds a spherical-cap cavity truncated at ±discH/2, and the disc carries the equatorial belt as solid dielectric with a central bore. Cap, belt, and bore volumes are reported.

### 7.2 Key / hub sizing (DIN 6885) **[OC math; IR for the 1.5·D rule]**
Two stub shafts (one per apex). Key length is auto-sized by the load-distribution rule **L ≈ 1.5·shaft⌀**, snapped *up* to the nearest DIN 6885 standard length; a DIN 6885 cross-section table provides key width and hub keyway depth. In the **standalone** mode the hub diameter is *derived* from the assembly footprint:

```
hubDia (key sizing) = voidDia + shaftDia + 2·keyLen − discH   (= 2·R_c)
```

### 7.3 Feasibility guards
Each guard reports a signed margin; the binding (most-limiting) guard is named. Hard guards (red when violated) / soft guards (amber):

- **collar:** shaft⌀ ≤ R_c
- **void seat:** shaft⌀ ≤ 2·insertion depth
- **wall:** voidR ≤ (R_c/√2)·(1 − wall-fraction)
- **key fit:** keyed length ≥ key length
- **keyway collar** (soft): R_c − shaftR − hub-keyway-depth ≥ shaftR
- **hub fits ring** (coupled mode only — see §8)

Additional warnings cover caps vanishing (disc thickness ≥ void⌀), an over-wide bore, and the coupling checks.

### 7.4 High-voltage geometry (distances only) **[OC geometry]**
By mirror symmetry the void centre is the electrical neutral. The tool reports straight and surface distances but **does not assert a safe voltage** (deferred):

```
clearN  = voidR                          (electrode → central neutral)
clearEE = 2·voidR                        (electrode → electrode, through the void)
creepEE = 2·(voidR − bore/2) + discH     (surface path around the septum bore)
```

### 7.5 Live axial cross-section
A canvas slice through the shaft axis, mirrored left/right and top/bottom, redrawn on every recompute. It is **isotropic** (equal px/mm on both axes) so proportions are true, with a `fit | lock-scale` toggle, a millimetre **scale bar** + px/mm readout (necessary because the disc is wide and flat while the cones are small), and an optional **dimensions** overlay. Features are colour-coded and turn red when their guard trips, so the drawing doubles as the guard visualiser. It renders: the dielectric disc, the sectored electrodes (hatched annular bands), the two quadricone profiles, the spherical-void caps + septum belt + bore, the two shaft stubs with keyway, the central neutral marker, and the **fixed stator plates** above and below the rotor (annular bands at the gap g from each electrode, with stator ⌀ = rotor/plate ⌀, clearing the hub centrally).

---

## 7A. Block R — central resonator (resonant tank)

Models the high-frequency `C_R ∥ L` tank that the charge pump excites. **Independent producer** — it never feeds the solver.

### 7A.1 Topology
Two conical coils are wound on the quadricones (one per cone) and connected in series, aiding, apex-to-apex; they bridge the two rotor electrodes. A **through-mica capacitor `C_R`** bridges the same two nodes (the electrodes are held **fully aligned** — the locked design premise — so the antiphase pumping comes from *stator* offset and a real inter-electrode capacitor exists). `C_R ∥ L` is a parallel tank that rings at `f0` and decays with `τ` after each drive pulse.

### 7A.2 Inductance (conical loop-stack) **[OC]**
A single-layer 45° conical helix is treated as an exact stack of coaxial circular loops (pitch = conductor OD + 2·insulation; turns per cone = ⌊slant/pitch⌋). The series inductance is the sum of every loop's HF self-inductance plus twice the Maxwell **mutual inductance** of every loop pair:

```
L = Σ Lself(r_k) + 2·ΣΣ_{i<j} M(r_i, r_j, |z_i − z_j|)
Lself = μ0·r·(ln(8r/a) − 2),   M via complete elliptic integrals K,E (AGM, no library)
```

For very large turn counts the stack is decimated to ≤ 400 nodes for live recompute (flagged). The engine was cross-checked against the Nagaoka/Wheeler solenoid value.

### 7A.3 Capacitance, resonance, loss **[OC; Cself is IR]**
```
C_R = ε0·εr_mica·A_align / discH        (through the mica septum; A_align from the corrected C-I area)
Ctot = C_R + Cself + stray              (Cself = Medhurst estimate, usually negligible)
f0 = 1/(2π√(L·Ctot)),  Z0 = √(L/Ctot),  τ = 2L/R_ac,  f_d = f0·√(1 − 1/4Q²)
δ = √(ρ_cu/(π f0 μ0)),  R_ac = ρ_cu·length/(π·OD·δ)   (current on the outer surface at HF)
```

**Conductor input:** wire (AWG ⇄ ⌀ ⇄ area), tube (OD/ID), or a manual OD. A verified consequence of the skin effect: a **capillary tube ≈ a solid rod** of the same OD in L, C, f0, Z0 and Q (identical RF behaviour) at far less copper and mass — the `wire | tube` toggle shows this directly.

> **Q is copper-only and an upper bound.** The reported Q counts only conductor loss. Real Q is dominated by mica dielectric loss (tanδ) and spark-gap/diode loss, both deferred; the figure is labelled an upper bound and **not** asserted as the operating Q.

### 7A.4 Drive from rotor speed **[OC kinematics; IR regime reading]**
With ⌈Nsec/2⌉ capacitance phases per revolution:
```
prf = ⌈Nsec/2⌉·rpm/60,   ring cycles = f0/prf,   settle = τ·prf
```
Since `prf ≪ f0`, the tank is not driven at resonance — each pulse triggers a ringdown. `settle < 1` = rings decay between pulses (isolated); `settle > 1` = successive rings overlap (build-up). The `settle ≈ 1` boundary is the headline drive output.

### 7A.5 Cross-section + legend
Block R draws the coil onto the shared cross-section as a copper band hugging each cone slant (per-turn hatch; tube vs wire indicated; turns red if the coil guard trips), and introduces a **colour + hatch legend** that keys every drawn region (coil, electrodes, stators, mica disc, hubs, void, shafts) to the readouts that describe it.

---

## 8. Coupling between the geometry blocks **[IR — user-directed]**

The electrical plate (C-I) and the mechanical core (M) are linked by a toggle ("couple to plate", on by default; shareable in the URL). The two diameter families are kept distinct — an *outer* electrical family and an *inner* mechanical family — and tied as:

```
plate ⌀ (C-I)        →  structural disc ⌀ (M)        [outer family]
ring-outer ⌀ (C-I)   →  quadricone / hub ⌀ (M):  hubDia = ring-outer⌀,  R_c = hubDia/2   [inner family]
sectors (C-I)        →  primary structural input, surfaced in M (12 → 6 kept/6 gap, etc.)
```

The key consequence: in coupled mode the hub is **no longer derived from key sizing**; it is set by the capacitor ring. The DIN key/void/shaft sizing then becomes a **boundary condition** checked by a hard guard — *"hub fits ring (key sizing ≤ ring ⌀)"* — which goes red if the chosen void/shaft/key assembly will not fit inside the ring-imposed hub. In coupled mode the structural disc-⌀ input is disabled and tracks the plate, and the electrode is reported explicitly as the annulus [hub⌀, plate⌀] over the chosen sector count.

> The two implementation briefs originally specified this link as *warn-only* ("do not hard-link"). The active coupling was added on explicit instruction and recorded as a deliberate change in the changelog, per the project's "correct openly" convention.

---

## 9. Data flow and what is user-set vs. derived

| Quantity | Source |
|:--|:--|
| Sector count, plate ⌀, ring ⌀ (in/out), gap g, dielectric + (T, P, RH) | **User input** (Block C-I) |
| Rotor caps C1/C2 min & max | **Derived** from C-I capacitance (inherited; inputs disabled) |
| Transfer caps Ca, Cb; stray Cpar | **User input** (cannot be estimated yet) |
| Void ⌀, bore ⌀, disc thickness, shaft ⌀, wall fraction | **User input** (Block M) |
| Disc ⌀ | **Derived** from plate ⌀ when coupled (else user input) |
| Hub ⌀ / cone radius | **Derived** — from ring ⌀ when coupled, else from key sizing |
| Key length + DIN size, keyed length, clearances, creepage, volumes, guard margins | **Derived** (Block M) |
| Conductor type (wire/tube/manual OD), gauge/tube ⌀, insulation, rotor RPM, stray C, pulse V | **User input** (Block R) |
| Turns, L, C_R, Ctot, f0, Z0, Q, τ, R_ac, δ, PRF, settle/regime | **Derived** (Block R) |
| Doubling ratio z and all electrical outputs | **Derived** (host solver) |

**Worked default device (loads on open):** 12 sectors, 1 m plate/disc, ring-outer ⌀ 150 mm → hub ⌀ 150 mm / cone radius 75 mm, gap 0.5 mm, air; void 40 mm, shaft 20 mm, disc thickness 10 mm; resonator on a 3 mm/1 mm capillary tube at 3000 rpm. This yields inherited rotor caps **Cmin ≈ 278 pF, Cmax ≈ 7080 pF** (swing ratio ≈ 25), all mechanical guards green (binding guard: key fit), HV spans clearEE = 40 mm / creepEE = 30 mm, and with Ca = Cb = 100 pF, Cpar = 20 pF a doubling ratio **z ≈ 1.25** (pumping); the resonator tank computes **L ≈ 123 µH, C_R ≈ 1.9 nF, f0 ≈ 326 kHz, Z0 ≈ 260 Ω, copper-Q ≈ 1000 (upper bound)**, PRF 300 Hz, settle ≈ 0.3 (isolated ringdown). *(These defaults were chosen so the coupled mechanical guards land valid; they are a starting point, not a recommended operating point.)*

---

## 10. User interface

Dark, monospaced, single-column-collapsing layout. Three input panels (rotor plate geometry; rotor mechanical core; rotor caps + transfer/stray) and an outputs panel (z display, verdict, growth metrics, headroom meter) plus charts. Every numeric control is a linked slider + number box with explicit units and a min/max range. Presets are provided: electrical (`device`, `wide`, `narrow`, `no swing`), plate-only dielectric exploration (`plate · air`, `plate · mica`), and the coupled `rotor-core` showcase. State is shareable via "copy share-url".

---

## 11. Verification — self-tests

The page runs a deterministic self-test suite on load and shows pass/fail in an expandable table; the engine badge reflects the aggregate. The suite has three groups, **all currently passing**:

**Electrical engine (host):**
- four reference operating points (no-swing → z ≈ 1.000; device → z ≈ 1.203; narrow → z ≈ 1.000; wide → z ≈ 1.438), each within tolerance;
- a C1↔C2 swap-symmetry check (swapping the two rotors must not change z).

**Block C-I (capacitance):**
- dry-air permittivity at 0 °C / 1013 hPa / 0 % RH → εr ≈ **1.000576** (matches the textbook value);
- a fixed-geometry capacitance check (10 cm plate, 12 sectors, ring off, 0.1 mm gap, vacuum) → Cmax ≈ **347.7 pF**, compared against an independently computed closed-form value.

**Block M (mechanical):**
- hub-diameter formula: void⌀ 50, shaft⌀ 35, disc thickness 0 → hub⌀ = **197 mm**;
- void-partition identity: two spherical caps + equatorial belt = full sphere (degenerate bore);
- DIN key sizing: keyLenFor(35 mm) → **DIN 56**.

**Block R (resonator):**
- elliptic integrals: K(0) = E(0) = **π/2** (AGM);
- capillary tank: **C_R ≈ 1.91 nF** and **L ≈ 131 µH** (the validated loop-stack value);
- skin-effect identity: tube OD3/ID1 vs solid rod OD3 → **equal f0 and Q**;
- AWG conversion: AWG 20 → **0.812 mm**;
- drive kinematics: PRF(12 sectors, 3000 rpm) = **300 Hz**.

These checks are deterministic and serve as a clean pass/fail gate for any change.

---

## 12. Assumptions, idealisations, and limitations

- **Ideal switched-capacitor model.** The solver uses ideal diodes (no forward drop, no leakage, no reverse recovery) and lossless capacitors. z is an asymptotic, steady-state ratio, not a transient or efficiency figure.
- **Fringing neglected.** The capacitance uses the ideal parallel-plate law; a warning fires when the gap is no longer small compared with the smallest in-plane feature, but no fringing correction is applied.
- **No breakdown / safe-voltage limit.** HV distances (clearance, creepage) are reported as geometry only. The tool deliberately does **not** convert them into a safe operating voltage; dielectric strength and leakage are a separate, deferred block.
- **Rotary-dielectric caveat.** Solid dielectrics (mica/Kapton) are not physically rotatable against both plates; they are flagged as fixed-gap exploration.
- **No mass / inertia / balance.** Rotational dynamics, mass, and static balance are out of scope (a later "flywheel" block).
- **Coupling is geometric, not enforced as a tolerance stack.** Plate ≈ disc and ring = hub are set as equalities; manufacturing tolerances are not modelled.
- **Defaults are illustrative.** The loaded default device is chosen to be self-consistent (all guards green), not to represent an optimised or recommended design.
- **Validation status.** All verification is internal/analytic (self-tests against closed-form values and reference points). The tool has **not** been validated against physical hardware.

---

## 13. Epistemic discipline (tier tags)

Every substantive statement in the documentation and every modelling choice in the code carries a tag, kept deliberately honest:
- **[OC] Operational Core** — standard, derivable physics/math, true independent of this project.
- **[IR] Interpretive Reading** — an engineering/modelling choice; internally consistent, chosen rather than forced.
- **[RH] Resonance / Heuristic** — suggestive only, not load-bearing.

This lets an external reviewer immediately distinguish textbook results (the capacitance law, the doubler solver, the geometry, DIN sizing, the air model) from design decisions (treating solids as constant, the raise-max field policy, the plate↔core coupling, rendering choices).

---

## 14. Reproducibility, provenance, and change control

- **Reproducible by URL.** Any computed state is fully captured in the page URL hash; sharing the link reproduces the inputs and therefore the outputs exactly.
- **No hidden state.** No `localStorage`, no cookies, no server; the page is deterministic given its inputs.
- **Auditable history.** Source is under version control with a human-readable `CHANGELOG.md`; the implementation briefs (`docs/brief-blockC1-…`, `docs/brief-blockM-…`) and conventions (`CONVENTIONS.md`) are part of the repository.

---

## 15. Symbol glossary (selected)

| Symbol | Code | Meaning |
|:--|:--|:--|
| C1, C2 | `c1*`, `c2*` | the two antiphase rotor capacitors (min/max) |
| Ca, Cb | `ca`, `cb` | fixed transfer capacitors |
| Cpar | `cpar` | per-node stray capacitance to ground |
| z | — | asymptotic per-cycle doubling ratio |
| Nsec | `pnsec` | sector count (12 → 6 kept / 6 gap) |
| g | `pgap` | capacitor gap (electrode ↔ stator) |
| εr | `epsR` | relative permittivity (dielectric) |
| Cmin, Cmax, κ_C | — | rotor capacitance extremes and swing ratio (= host r₁/r₂) |
| R_c, hub⌀ | `coneR`, `hubDia` | cone base radius; hub diameter = 2·R_c |
| voidR, discH | — | spherical-void radius; disc thickness |
| clearN/EE, creepEE | — | HV clearance and creepage distances |

---

## 16. Open items / roadmap

1. **Dielectric strength → safe-voltage bound** across the reported clearance/creepage (the genuine next block; couples C-I dielectric to M geometry).
2. **Conduction / leakage loss** in the doubler (moves z from ideal toward realistic).
3. **Fringing correction** for non-small gaps.
4. **Mass / rotational inertia / static balance** (flywheel block).
5. **θ-sweep visualisation** of C(θ) (the solver only needs the two extremes; this is illustrative).
6. **Estimating the transfer/stray capacitances** from geometry (currently the only required manual electrical inputs).

---

*End of report.*

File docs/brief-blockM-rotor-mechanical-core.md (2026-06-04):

# Brief — Block M: Rotor Mechanical Core (Quadricone + Shaft + Void + Disc)

**For:** Claude Code (implementation agent)
**Host:** `index.html` — Symmetric Bennet Doubler 4-node calculator (vanilla JS, self-contained). **Integrate as a parallel panel.**
**Status:** specified, not yet implemented. `[OC]` for the geometry/math; `[IR]` for device/assembly choices; `[RH]` for the operating-field reading.

> Discipline + symbol hygiene: see `CONVENTIONS.md`. The geometry below is mainstream solid mechanics; **no DCCREG theory is included or required** (README firewall).

---

## 0. Inheritance & relation to Block C-I

- **From C-I (`brief-blockC1-...`):** the rotor plate is a **sectored-disc + ring** capacitor electrode producing `Cmin/Cmax`. Block M supplies the *structural body* that electrode rides on. **Block M is a second, independent producer; it does NOT feed `solveDoubler4`.** **[OC — producer/consumer preserved]**
- **From the host:** match `FIELDS`/`state`/`$()`/`bindField`/`scheduleRecompute`/hash idiom; CSS-variable dark theme; on-load self-tests. **[match it]**

**The rotor (physical picture).** A central dielectric **disc** carries a sectored capacitor **electrode on each face** (C1 top, C2 bottom), mirrored across the disc mid-plane. Each electrode is a sectored annulus: inner edge at `hubDia` (the cone base), outer edge ≈ `plateDia ≈ discDia`. A **45° quadricone half** is bonded to each electrode across that annulus, base-to-electrode; the cone tapers outward to its apex, where a **stub shaft** (one per side — never a through-shaft) couples it to a bearing/drive. A **spherical void** sits at the assembly center; the disc fills its equatorial belt as a dielectric **septum** with a small central bore. Two sectored groups offset by one sector pitch realise the host's antiphase C1/C2. **[IR — assembly realisation]**

---

## 1. Symbols (additions to `CONVENTIONS.md` §2)

`d` remains **forbidden**. Two diameter families — outer (`discDia ≈ plateDia`) and inner (`hubDia = 2·coneR`); explicit `*Dia` names.

| Quantity | Symbol | Code | Notes |
|:--|:--|:--|:--|
| Cone base radius (= hub radius) | $R_c$ | `coneR` | 45° ⇒ cone height = `coneR` |
| Hub diameter (= electrode INNER annulus) | $\varnothing_h$ | `hubDia` | $=2R_c$; set by key sizing (small) |
| Disc diameter (structural, outer) | $\varnothing_D$ | `discDia` | large; carries the electrodes |
| Plate / electrode OUTER diameter | $\varnothing_p$ | `plateDia` | $\lesssim$ `discDia`; C-I owns it |
| Void radius / diameter | $r_v,\varnothing_v$ | `voidR`,`voidDia` | sphere; centred on the disc mid-plane |
| Disc thickness | $H_d$ | `discH` | separates C1/C2; **not** `h` bare |
| Disc central bore diameter | $\varnothing_{dv}$ | `discVoidDia` | dielectric-septum passage; ex. $\approx\varnothing_v/2$ |
| Wall fraction (void budget) | $f_w$ | `wallFrac` | $[0,1]$; **not** `t` (temperature) |
| Shaft diameter / radius | $\varnothing_s$ | `shaftDia`,`shaftR` | stub, one per cone apex |
| Key length / width | $L_k,w_k$ | `keyLen`,`keyW` | DIN 6885 |
| Hub keyway depth | $t_2$ | `keywayHubT` | collar reduction |
| Insertion depth (per stub) | $L_{ins}$ | `insertDepth` | apex → bore bottom |
| Collar (radial, at base) | — | `collar` | $=R_c-\text{shaftR}$ |
| Cone cap depth (void, per cone) | $c$ | `capDepth` | $=r_v-H_d/2$ |
| Electrode↔neutral clearance | — | `clearN` | $\approx r_v$ |

---

## 2. Quadricone geometry (port to vanilla JS)  **[OC]**

45° half-angle ⇒ for each cone, height = `coneR`; one cone solid $=\tfrac13\pi R_c^3$.

```
volQuadricone = (2/3)*PI*coneR^3            // both cones (no disc/void/shaft yet)
```

**Void (spherical) + wall guard.** Sphere radius `voidR`, centred at the disc mid-plane.
```
voidR <= (coneR/sqrt2) * (1 - wallFrac)     // inscribed-sphere wall budget
```

**Disc compensation — caps stay spherical, disc is the septum.** With the disc of thickness `discH`, each cone holds a **spherical cap** truncated at `±discH/2`; the disc carries the equatorial belt as **solid dielectric** with a central bore `discVoidDia` (NOT an open zone).
```
capDepth = voidR - discH/2                  // per cone; valid while discH < voidDia
```
The two cap cavities connect only through the disc bore. The electrode-facing cap surface is exactly spherical; the belt 12.5–25 mm (ex.) is dielectric. **[IR for the septum; OC for the cap]**

---

## 3. Shaft / key / hub sizing  **[OC math; IR for the 1.5·D rule]**

Two **stub** shafts, one per apex (a through-shaft would short C1↔C2). Apex sits at `coneR + discH/2` from centre; void pole at `voidR`, so the disc *adds* `discH/2` of insertion room per side:
```
insertMax = coneR + discH/2 - voidR         // bore must clear the void pole
keyedLen  = insertMax - shaftR              // collar exists only beyond shaftR depth
```
**Key auto-sizing (industry).** Equal-strength length ≈ **1.571·shaftDia**; practical rule **L ≤ ~1.5·shaftDia** for load distribution. Default `keyLen = 1.5*shaftDia`, round to a DIN 6885 standard length. **[OC]**

**Hub sizing (key binds at this scale):**
```
hubDia = voidDia + shaftDia + 2*keyLen - discH        // = 2(coneR)
```
**Guards (hard stop in red; warn in amber):**
```
collar:        shaftDia <= coneR                         // hub OD >= 2*bore  [hard]
void seat:     shaftDia <= 2*(coneR + discH/2 - voidR)   // clean stub seat   [hard]
wall:          voidR <= (coneR/sqrt2)*(1 - wallFrac)     // [hard]
key fit:       keyedLen >= keyLen                        // [hard]
keyway collar: coneR - shaftR - keywayHubT >= shaftR     // [warn]
```

---

## 4. Assembly stack-up & shared parameters (Block M ↔ C-I coupling)  **[IR]**

Two diameter families (outer electrical, inner mechanical) plus the void tie the models together. **Coupling is warn-only** (do NOT hard-link the panels):
```
// TWO diameter families — do NOT collapse them:
discDia  ≈ plateDia          // OUTER (electrical): set by capacitor area / C-I  (ex. 1000 ≈ 998)
hubDia   = 2*coneR           // INNER (mechanical): set by key sizing             (ex. 150)
electrodeInnerDia = hubDia   // sectored electrode = annulus [hubDia, plateDia]
hubDia >> voidDia > discVoidDia   // void + bore are small central features inside the hub
```
- **Warn** if the C-I plate's effective inner radius ≠ `hubR` (the electrode should ring the hub). **[warn]**
- **Warn** if `plateDia > discDia` (electrode overhangs the disc). **[warn]**
- The void/septum live inside `hubR`; the electrode lives outside it — they do not overlap. **[OC]**

**HV separation (geometry only — voltage/breakdown is the deferred HV block).** Void centre = electric neutral by mirror symmetry; each electrode is ≈ `voidR` from it.
```
clearN   = voidR                             // electrode -> central neutral (straight)
clearEE  = 2*voidR (= voidDia)               // electrode -> electrode (through void)
creepEE  = 2*(voidR - discVoidDia/2) + discH // surface path around the septum bore
```
The disc bore `discVoidDia` is the neutral passage; the solid belt is the creep barrier. Report distances; **do not** assert a safe voltage (deferred). **[OC geometry; RH for "field-mediated conduction at working energy"]**

---

## 5. Outputs (new local panel; nothing driven into the solver)

`.kv` readouts: `coneR`, `hubDia`, `capDepth`, `insertMax`, `keyLen` (+ DIN size), `keyedLen`, `collar`, `clearN`, `clearEE`, `creepEE`, void/cap/septum volumes, and a binding-guard line (which constraint set `hubDia`). Mass / inertia / balance are **deferred** (later block). **[OC]**

Plus the **live axial cross-section** (§5.1) — the primary visual feedback for this block.

---

### 5.1 Live axial cross-section (parametric, canvas)  **[OC geometry; IR rendering]**

A canvas slice through the **shaft axis** — the $(x,z)$ half-plane mirrored left/right (about the axis) and top/bottom (about the disc mid-plane) — redrawn live on every `recompute`. It frames the *current* geometry so proportions visibly morph as parameters change. This is the block's main visual readout.

**Projection.** `z` vertical (shaft axis), `x` = signed radius. **Isotropic** scale (equal px/mm both axes) so proportions are true:
```
totalH = discH + 2*(coneR + stubOut)
scale  = min( (W-2*m)/discDia, (H-2*m)/totalH )      // m = margin px
```
Re-fit each redraw (the "parametrically sized" behaviour). Because the disc is wide and flat (ex. 1000 mm) while the cones are small (ex. 150 mm), show a **mm scale bar** + `px/mm` so absolute size stays legible under auto-fit. A `fit | lock-scale` segmented toggle is desirable — **lock** makes changes read as real growth/shrink instead of re-framing. **[IR]**

**Elements (host CSS vars).** Dielectric disc (rect `x∈[±discR]`, `z∈[±discH/2]`, `--panel`/`--line`); sectored electrodes as bands on both faces over `x∈[±hubR,±plateR]` (`--acc`, hatched to denote "sectored"); the two 45° quadricone profiles (triangles, base `±coneR` at `±discH/2`, apex on axis), `--ink`/`--dim`; the spherical **void** caps (arcs radius `voidR`, drawn as cavity), the dielectric **septum belt** (`discVoidR→voidR`) and the central **bore** (`±discVoidR`); the two **shaft stubs** (rects `±shaftR`, bore depth `insertMax` inward, protruding outward) with a **keyway** notch; the central **neutral** marker at the origin; optional dashed **creepage** path and the `clearEE` span.

**Dimension annotations** (leader-lined, toggle-able): `discDia hubDia voidDia discVoidDia discH coneR insertMax`.

**Guard feedback.** Colour a feature `--bad` when its hard guard trips (cap vanishes at `discH ≥ voidDia`; shaft breaches collar; wall/key fail) and echo the binding-guard label. The cross-section thus doubles as the guard visualiser.

---
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

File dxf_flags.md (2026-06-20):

# DXF flags — r0.15 EE schematic (for the next drawing rev)

The r0.15 schematic is committed and confirms the deck graph (TOPOLOGY-CONFIRMED). One soft flag remains for cosmetic cleanup (does **not** block the lock):

## FLAG — ND7/ND8 label-position asymmetry (DXF, soft)

- ND7 label @ (1574.389168460322, 1436.72634823195), ND8 label @ (1855.705060494227, 1435.87167619824). Under the A/B mirror about the schematic centre (x=1793), ND8 should sit near x=2012 but is at x=1856 (~157 off). Every other node pair mirrors exactly.
- **Classification:** a label-POSITION asymmetry, not a proven connectivity error. The island ND8's connectivity (Cx4 8-2, SG4a 4-8, SG4b 8-2, BS4 2-8 — the group-B mirror of ND7) is coherent with freeze §5 and the deck. Likely a drafting-layout choice (the island body drawn at its physical position). **Action:** verify the ND8 label/body placement in the next rev for visual symmetry; no deck change needed.

## Method note (not a flag)

The doubler/commutation symbols are drawn as raw primitives (lines/circles/splines), not blocks with named terminals, so an isolated per-symbol terminal trace is not robustly extractable. Those edges are confirmed by node-layout + symmetry + freeze §5 + the spatially-separable traced subset (C_R, SG1, SG2, C2). For a future fully-automated net-for-net diff, drawing the components as blocks with attributed terminals would let the tracer resolve every edge unambiguously.
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

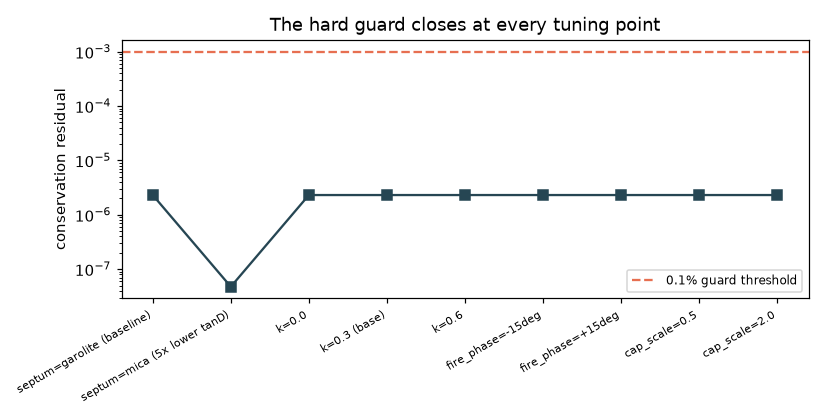
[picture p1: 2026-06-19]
s8_conservation_guard.png

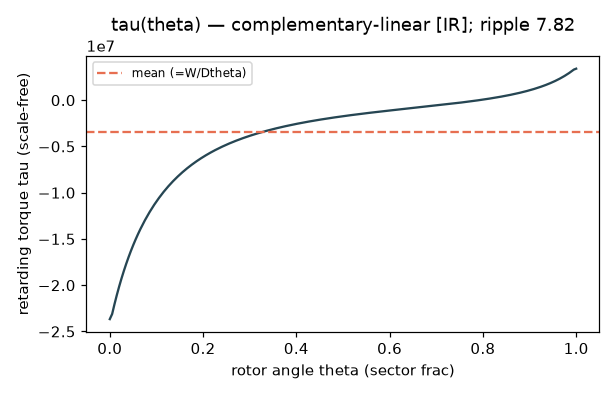
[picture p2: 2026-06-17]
energy_balance_tau.png

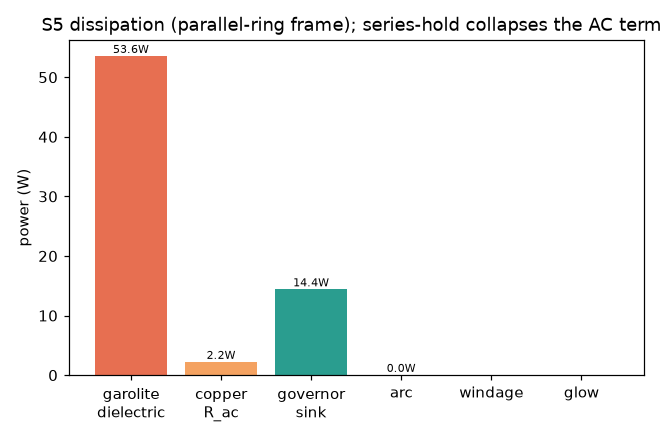
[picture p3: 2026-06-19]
s5_dissipation_budget.png

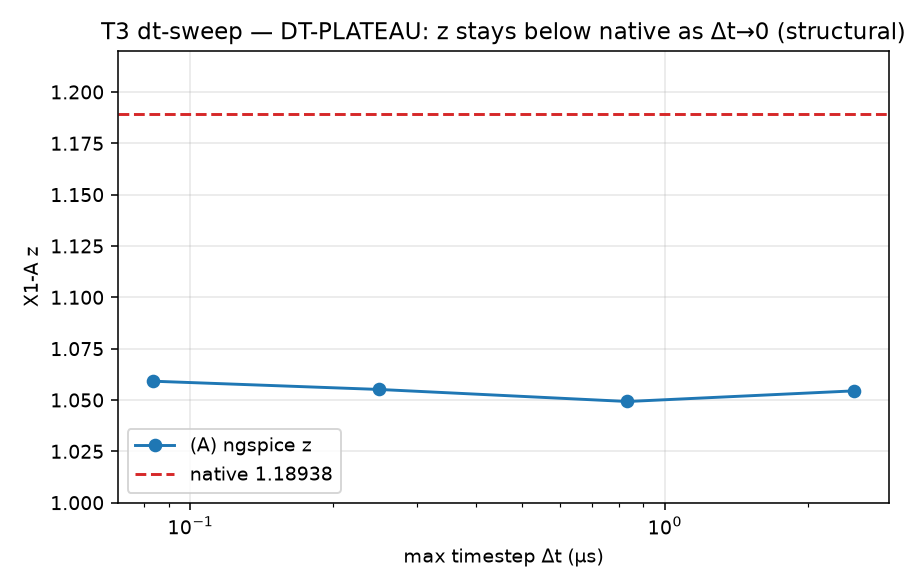
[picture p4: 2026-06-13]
xsim_dt_sweep.png

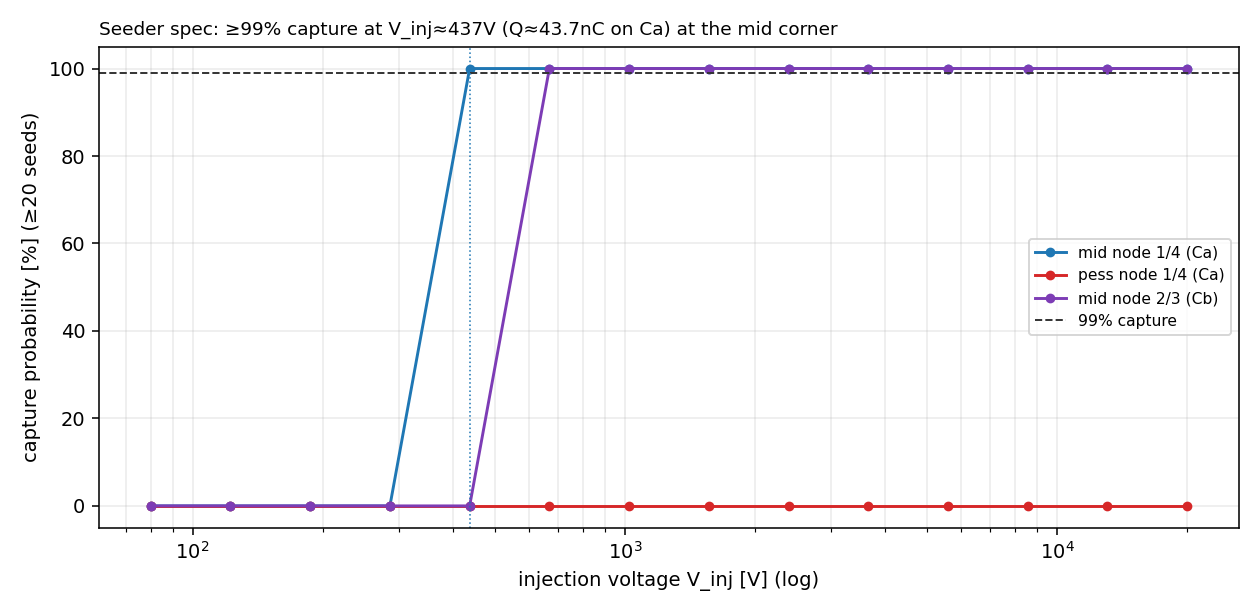
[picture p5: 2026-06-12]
bootstrap_capture_window.png

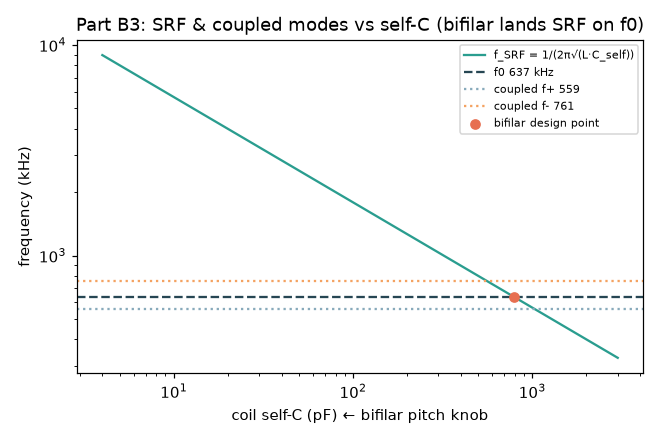
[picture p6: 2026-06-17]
coil_srf_modes.png

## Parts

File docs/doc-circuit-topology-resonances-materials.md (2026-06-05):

# System Documentation — Circuit Topology, Multiple Resonances & Materials

**Scope:** the machine as a whole — the full circuit topology, the three coexisting frequency regimes and the resonant circuits living in them, how those resonances relate to each other and to RPM, the start-up and equilibrium behaviour, and the materials and their effects. This is the integrating document that the per-block briefs (C-I, M, R, D) plug into.

**Companion docs:** `brief-blockM-rotor-mechanical-core.md` (mechanical core), `brief-blockR-central-resonator.md` (central LC tank), `brief-blockD-distributed-electromagnets.md` (spin-up motor). Cross-references below use those block letters.

---

## Revision history

| Version | Date | Summary |
|---|---|---|
| v0.1 | 2026-06-05 | Initial system doc. 6-node topology + two-spinning-unit architecture; three-frequency map; the central f0 tank and the per-coil C-EM resonance and their RPM relationship; impedance hierarchy; start-up bootstrap and the two thresholds; materials section (iron rotor, laminated cores, copper, mica, HV caps). |

---

## Tier legend

- **[OC]** Operational Core — standard physics/EE.
- **[IR]** Interpretive Reading — a design choice within this machine.
- **[RH]** Rhetorical/Heuristic — framing, not load-bearing.

---

## 1. Circuit topology

### 1.1 Two self-contained spinning units, coupled only by capacitance

The machine is two independently rotating assemblies:

- **Rotor unit** — belt-driven (the prime mover). Carries the rotor electrode halves (nodes **5–6**), the central resonator coil, and the solid-iron quadricone poles. Self-contained: its internal wiring closes on itself.
- **Stator unit** — free-spinning, counter-rotating. Carries the stator electrode halves and pump nodes **1–4**, and the 12 C-EM coils. Also self-contained.

They share **no galvanic connection**. All energy crosses the gap **capacitively, through the variable capacitors** (the varicaps). Because the coupling is capacitive, **neither unit needs slip rings** — this is the architectural keystone. The commutation that a brushed/slip-ring machine would need is instead **integrated into the charge pump**: the varicaps reach C_max/C_min at rotor-angle-defined instants, which is what times the charge transfers. [IR]

### 1.2 The 6-node netlist

```
 Ca : 1–2     fixed transfer cap        (= "C3" in the C-EM brief)
 Cb : 3–4     fixed transfer cap        (= "C4" in the C-EM brief)
 C1 : 1–5     variable cap (varicap)    rotor-coupling
 C2 : 4–6     variable cap (varicap)    rotor-coupling
 D3 : 1–3     cross-couple diode (or SG3)
 D4 : 4–2     cross-couple diode (or SG4)
 D1 : 2–5     diode (or SG1)
 D2 : 3–6     diode (or SG2)
 L1 : 5–6     central resonator coil, with C_R (through-mica inter-electrode cap) implicit
 C-EMs        : 6 across Ca, 6 across Cb (Block D), each via its resonant DC-block cap
```

- Nodes **1, 4** are the outer varicap plates — the large HV swing, `|V1|+|V4|`. [OC]
- Nodes **5, 6** are the rotor electrodes — the resonator terminals. [OC]
- **Diode vs spark-gap:** build the **diode** version first (deterministic, self-starts from ambient seed). The spark-gap version (SG1–4, threshold-fired) is deferred — it needs a timing-diagram switch simulation. [IR]

### 1.3 The pump-rate short that keeps the doubler math valid

At the pump rate (~hundreds of Hz) the central coil L1 is a fraction of an ohm — effectively a short across 5–6, merging them into the common rail the original `solveDoubler4` gain analysis assumes. **The doubler gain math therefore stays valid as written;** the resonator is a high-frequency layer riding *on top* at f0 (§2). This is why the central coil is deliberately the **low-L** element of the machine. [OC/IR]

---

## 2. Three frequency regimes — the map

Every impedance statement in this machine is meaningless without naming its frequency, because the same coil looks utterly different at each. There are three regimes, separated by ~1000× each step:

| Regime | Typical value | Origin | What lives here |
|---|---|---|---|
| **Mechanical / PRF** | ~150–450 Hz | rotation: `PRF = 6·RPM/60` | charge pumping; C-EM motor torque |
| **C-EM resonance** | = drive freq (PRF or PRF/2) | `L_coil` + `C_block` series | motor torque tuning + DC block |
| **Central f0 tank** | ~238 kHz | `L1` ∥ `C_R` | the HV "ring" |

The mechanical/PRF regime and the f0 regime are ~1000× apart. The pump kicks the tank a few hundred times per second; between kicks the tank rings at ~238 kHz and decays. They do not interfere precisely because of that separation. [OC]

> **f0 note.** With the motor coils properly isolated (high-L, real spectators at f0), they do **not** load the central tank, so f0 stays at the central-coil-alone value **≈ 238 kHz** (L1 ≈ 235 µH with C_R ≈ 1.9 nF). The earlier "≈ 290 kHz" figure assumed the EM coils sat *inside* the tank (~430 µH parallel) — that loaded case is **superseded**, because steel-cored coils carrying 238 kHz current would be skin-dead and lossy and would wreck the tank Q (§5). Isolation is the deliberate choice; 238 kHz is the resulting f0. [OC/IR]

---

## 3. The multiple resonant circuits and how they relate

### 3.1 Resonance A — the central tank (the "ring"), RPM-independent

```
f0 = 1 / (2π·√(L1·C_R)) ≈ 238 kHz
L1 = central resonator coil (Block R), ~235 µH  (LOW-L element)
C_R = through-mica inter-electrode capacitance, ~1.9 nF
```

`f0` is set purely by L and C — **it does not move with RPM.** What RPM changes is the *amplitude* of the ring (more PRF kicks/sec at higher HV → bigger ring), not its frequency. Tunable only by the coil (turns/wire/cone size) and the disc cap (area, mica εr, thickness). [OC]

### 3.2 Resonance B — the C-EM coupling LC (torque tuning), RPM-tracking

```
f_res(C-EM) = 1 / (2π·√(L_coil·C_block))
            = the coil drive fundamental (PRF or PRF/2 — Block D §4.4)
```

This one is **designed to track the drive**, i.e. to sit at the operating PRF (or PRF/2). Since `PRF = 6·RPM/60`, the *match* between this LC and its drive only lands at the **design RPM**. The cap (user target 440 nF/20 kV) forces `L_coil ≈ 0.64 H` at 300 Hz (or 2.56 H at 150 Hz) — the "many windings" coil. [OC/IR]

### 3.3 How A and B stay out of each other's way — the impedance hierarchy

The two resonances coexist on the same nodes without fighting because of how each coil's impedance lands in each regime:

| Element | Z @ PRF (~300 Hz) | Z @ f0 (~238 kHz) | Role |
|---|---|---|---|
| Central coil L1 (~235 µH) | ~0.44 Ω — near-short | ~350 Ω — tank reactance | the resonator inductor; PRF short keeps doubler math valid |
| C-EM coil (~0.64 H) + C_block | ~R_coil at resonance — carries torque current | ~kΩ–10s kΩ — spectator | motor; resonant at PRF, invisible at f0 |
| C-EM block cap (440 nF) | resonates with coil | inductive branch above resonance → high-Z | DC block + torque tuning + f0 isolation in one part |

The separation is structural: the motor coils are sized for a useful Z at the **PRF** (torque), which — because f0 is ~1000× higher — automatically makes them ~1000× higher-Z at f0, i.e. spectators that neither shift f0 nor drain the ring. Conversely the central coil is the low-L element: a short at PRF (good for the pump), the reactance at f0 (good for the ring). [OC]

### 3.4 The voltage-magnification coupling (the one real cross-talk)

The C-EM resonance is series-resonant, so it magnifies the **cap** voltage by Q:

```
V_cap,peak = V_bias + Q·V_ripple ≤ V_rating   (Block D §4)
I_circ     = Q·I_input                         (current gain — the point of resonance)
```

This couples the **doubler output voltage** (which sets `V_bias` across the block cap) to the **motor cap rating**: the higher the doubler runs, the less AC headroom the 20 kV cap has, and the smaller the allowable ripple and torque. The torque-limiting ampere-turns reduce to a clean closed form (Block D §4.3):

```
N·I_circ,max = (V_rating − V_bias)·√(C_block·l_gap/(μ0·A_gap))
```

— independent of frequency and turns. So the real system trade is **doubler voltage vs spin-up torque**, mediated by the motor cap rating. Run the doubler well below the cap rating, or rate the caps above the doubler voltage. [OC/IR]

---

## 4. RPM dependence and the operating regimes

### 4.1 What scales with RPM and what doesn't

- **PRF = 6·RPM/60** — scales linearly. Sets the pump throughput, the motor commutation rate, and the C-EM drive frequency. [OC]
- **f0 (central tank)** — fixed by LC, **independent of RPM**. RPM changes ring *amplitude*, not frequency. [OC]
- **C-EM resonance match** — lands only at the design RPM (its LC is fixed, its drive tracks RPM), so **torque peaks at the design RPM and falls off either side.** This is a *feature*: it makes the machine tend to self-lock at the design speed, but it means weaker torque during low-RPM spin-up, which the belt must carry through. [OC/IR]

### 4.2 Start-up bootstrap (the chain)

1. Belt spins the rotor; stator starts at rest → relative speed = rotor speed.
2. Climb to **rpm_min** — the speed at which pump gain per stroke beats leakage/loss per stroke (set by leakage τ vs modulation period). Below it, charge bleeds off faster than it's pumped and nothing builds. [OC]
3. **Seed the pump.** A spark-gap doubler cannot self-start from zero (with Q=0, voltage never reaches any gap threshold). Inject a seed charge at the **C_max** rotor position, so the following rotation toward C_min drives `V = Q/C` up into the first gap's threshold on the first stroke. The **diode** version self-starts from ambient seed (contact potential / triboelectric) + modulation gain — a real start-up advantage. [OC]
4. HV builds → nodes 1–4 swing → C-EMs driven → stator counter-rotates → relative speed and PRF climb → bigger kicks into the f0 tank.
5. **rpm_crit** is *not* where the tank "starts" to ring (it rings at f0 whenever kicked, at any RPM) — it is where the C-EM resonance match, the ring amplitude, and the counter-rotation torque all reach the level that balances stator drag. That balance point is the equilibrium. [IR]

### 4.3 Equilibrium and energy flow

At equilibrium the chain is: belt → rotor (mechanical) → reacts through the C-EM/iron coupling to counter-rotate the stator → raises relative speed → raises PRF → pumps the f0 tank harder. The "optimal transfer" knob is matching the motor's PRF-regime branch impedance to the stator's mechanical load line, so torque peaks near rpm_crit and then backs off to merely trimming drag. That impedance/load match (motor `L_coil`, `Q`, and the ampere-turn limit vs stator inertia + drag) is the next quantitative piece to derive, and it couples to the deferred flywheel/inertia block. [IR]

---

## 5. Materials and their effects

Material choice is dominated by **which frequency each part sees**, because eddy-current and skin effects scale steeply with frequency.

### 5.1 Rotor quadricones — solid iron is acceptable

The rotor poles only ever see the **mechanical/PRF** field variation (hundreds of Hz) and act as a **passive reluctance** rotor (no windings, no f0 current). Eddy loss and skin effect at a few hundred Hz are modest, so **solid iron is acceptable** — a major simplification (easy to machine, structurally strong, doubles as the shaft-coupling hub mass). If start-up torque ripple or rotor heating turns out significant, axial lamination is the fallback, but it is not required by the frequency alone. Use a high-permeability, high-saturation soft magnetic iron (e.g. low-carbon steel) so the reluctance contrast (salient pole vs gap) is large → steeper `dL/dθ` → more torque. [OC]

### 5.2 C-EM cores — must be laminated (or ferrite)

The C-EM cores carry the **motor commutation** flux at the PRF and, critically, must **not** carry f0. Two effects:

- **Eddy loss ∝ f²** in a conductive core → at the PRF (hundreds of Hz) a **laminated silicon-steel** core keeps loss acceptable; solid steel would already be lossy and would dissipate the motor drive. [OC]
- **Skin/penetration at f0:** at ~238 kHz the skin depth in steel is ~tens of µm, so the core is **skin-dead** — it cannot carry the field through its bulk and is purely lossy at f0. This is *why* the motor coils must be isolated from the f0 tank (high-L, §3.3): you never want 238 kHz flux in a steel core. [OC]

Use **laminated silicon steel** for the working PRF flux (thin laminations, grain-oriented if the flux path allows). If the commutation frequency is ever pushed high, **ferrite** (an insulator, negligible eddy loss) becomes the better core, at the cost of lower saturation. The coil's own high inductance also **self-filters**: it is high-Z at f0, so even residual f0 coupling drives little current into the core. [OC]

> **Open-core caveat.** A C-magnet with a working air gap is demagnetisation-limited: the effective permeability seen by the coil is set by the **gap**, not the iron's μ_r (apparent μ of order a few for an open path). Inductance is therefore **gap-dominated** — `L ≈ μ0·N²·A_gap/l_gap` — which is exactly the relation used in the Block-D turns budget. The iron mainly provides the low-reluctance return and the saturation ceiling, not the bulk of L. [OC]

### 5.3 Copper windings — skin depth and the many-turns/low-current choice

- At the PRF the copper skin depth is large (mm-scale), so solid fine wire is fully utilised — no need for litz at the drive frequency. [OC]
- The **central resonator coil** is the exception: it runs at f0 (~238 kHz), where the copper skin depth is ~134 µm. There the earlier finding holds — a **capillary tube behaves like a solid rod** at f0 (current rides the outer ~skin-depth shell either way), giving the same L/C/f0/Q with ~11 % less copper. [OC]
- The C-EM windings follow the **many-turns / low-current** strategy: the available pump current is small, so torque (∝ ampere-turns) is recovered by raising N rather than I. High N also delivers the high `L_coil` needed for f0 isolation. The cost is winding resistance (sets Q and copper loss) and a self-resonant frequency that must stay well above f0 (Block D §9). [OC/IR]

### 5.4 Mica dielectric (the C_R cap and the structural septum)

The central disc is mica: it is the **structural septum** carrying the aligned electrode on each face **and** the dielectric of the inter-electrode cap `C_R = ε0·εr·A_align/discThk`. Mica is chosen for high dielectric strength, low loss (high tank Q), thermal stability, and mechanical rigidity (it is also a load-bearing rotor part). `εr ≈ 5.4`; thickness and aligned area are the two `C_R` tuning knobs feeding f0. Low dielectric loss is what lets the f0 ring keep a high Q. [OC]

### 5.5 HV blocking / resonant caps — film, energy, safety

The Block-D series caps (440 nF / 20 kV target) should be **HV film** (low loss, stable, self-healing types preferred). Two material-driven realities:

- **Voltage rating must cover the resonant magnification, not just the bias:** `V_cap,peak = V_bias + Q·V_ripple` (Block D §4). The 20 kV rating exists to absorb the Q-magnified AC on top of the blocked DC bias.
- **Stored energy is large and lethal:** `½·C·V² = 88 J` per cap at 20 kV; twelve of them ≈ **1.06 kJ** on the spinning stator. This drives the per-coil-vs-per-group decision and mandates an interlock/bleed/safety regime (a dedicated HV-safety block is an open deliverable). [OC]

### 5.6 Material → frequency summary

| Part | Frequency seen | Material | Why |
|---|---|---|---|
| Rotor quadricones | PRF (mechanical) | solid soft iron | low loss at hundreds of Hz; reluctance contrast; structural |
| C-EM cores | PRF; must reject f0 | laminated Si-steel (ferrite if HF) | eddy ∝ f²; skin-dead at f0 → isolate |
| C-EM windings | PRF | solid fine Cu, many turns | large skin depth at PRF; many-turns/low-current |
| Central coil | f0 (~238 kHz) | Cu — tube ≈ solid rod | skin depth 134 µm; save copper |
| Disc / C_R | f0 + structural | mica | dielectric strength, low loss (Q), rigidity |
| Block / resonant caps | PRF, HV | HV film | low loss; rated for V_bias + Q·V_ripple |

---

## 6. Open system-level questions

1. **Drive-frequency mapping** (PRF vs PRF/2) — pins L_coil and N (Block D §4.4).
2. **Doubler-voltage vs spin-up-torque** trade via the motor cap rating (§3.4) — choose the operating bias.
3. **Motor-impedance ↔ stator-load match** at rpm_crit (§4.3) — couples to the flywheel/inertia block.
4. **Real tank Q** — dielectric + spark-gap + core residual losses, vs the copper-only optimistic Q from Block R.
5. **HV safety block** — interlock, bleed, energy containment for ~1 kJ of HV storage on a rotating assembly.
6. **Spark-gap timing simulation** — for the deferred SG version of the pump and seed injection.

---

*Status: integrating system documentation, v0.1. The per-block briefs (C-I, M, R, D) remain authoritative for their own internals; this document is authoritative for how they couple in topology, frequency, and material.*

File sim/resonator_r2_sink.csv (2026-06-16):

stage | type | placement/mode | V_glow_kV | V_crowbar_kV | Q | sink_W | event_index | t_s | E_event_J | E_cumulative_J
R2 | glow | void | 13 |  | 320 | 51.640 |  |  |  | 4.131241e-01
R2 | glow | void | 14 |  | 320 | 43.237 |  |  |  | 3.458940e-01
R2 | glow | void | 15 |  | 320 | 33.991 |  |  |  | 2.719307e-01
R2 | glow | void | 16 |  | 320 | 24.480 |  |  |  | 1.958392e-01
R2 | glow | void | 13 |  | 500 | 52.796 |  |  |  | 4.223653e-01
R2 | glow | void | 14 |  | 500 | 44.468 |  |  |  | 3.557434e-01
R2 | glow | void | 15 |  | 500 | 35.301 |  |  |  | 2.824099e-01
R2 | glow | void | 16 |  | 500 | 25.754 |  |  |  | 2.060342e-01
R2 | glow | void | 13 |  | 900 | 52.247 |  |  |  | 5.179784e-01
R2 | glow | void | 14 |  | 900 | 44.231 |  |  |  | 4.385136e-01
R2 | glow | void | 15 |  | 900 | 35.441 |  |  |  | 3.513663e-01
R2 | glow | void | 16 |  | 900 | 26.246 |  |  |  | 2.602044e-01
R2 | glow | island | 13 |  | 320 | 56.175 |  |  |  | 4.494000e-01
R2 | glow | island | 14 |  | 320 | 48.075 |  |  |  | 3.846000e-01
R2 | glow | island | 15 |  | 320 | 39.375 |  |  |  | 3.150000e-01
R2 | glow | island | 16 |  | 320 | 30.075 |  |  |  | 2.406000e-01
R2 | glow | island | 13 |  | 500 | 56.175 |  |  |  | 4.494000e-01
R2 | glow | island | 14 |  | 500 | 48.075 |  |  |  | 3.846000e-01
R2 | glow | island | 15 |  | 500 | 39.375 |  |  |  | 3.150000e-01
R2 | glow | island | 16 |  | 500 | 30.075 |  |  |  | 2.406000e-01
R2 | glow | island | 13 |  | 900 | 54.395 |  |  |  | 5.392800e-01
R2 | glow | island | 14 |  | 900 | 46.552 |  |  |  | 4.615200e-01
R2 | glow | island | 15 |  | 900 | 38.128 |  |  |  | 3.780000e-01
R2 | glow | island | 16 |  | 900 | 29.122 |  |  |  | 2.887200e-01
R4 | glow-upstream | full | 15 | 16 | 320 | 39.375
R4 | glow-upstream | full | 15 | 16 | 500 | 39.375
R4 | glow-upstream | full | 15 | 16 | 900 | 38.128
R4 | glow-upstream | eased | 15 | 16 | 320 | 4.375
R4 | glow-upstream | eased | 15 | 16 | 500 | 4.375
R4 | glow-upstream | eased | 15 | 16 | 900 | 4.236
R3 | crowbar | void |  | 15 | 320 |  | 0 | 0.000000e+00 | 1.680871e-01 | 1.680871e-01
R3 | crowbar | void |  | 15 | 320 |  | 1 | 1.666669e-03 | 1.680872e-01 | 3.361743e-01
R3 | crowbar | void |  | 15 | 320 |  | 2 | 3.333337e-03 | 1.680872e-01 | 5.042615e-01
R3 | crowbar | void |  | 15 | 320 |  | 3 | 5.000006e-03 | 1.680872e-01 | 6.723488e-01
R3 | crowbar | void |  | 15 | 320 |  | 4 | 6.666675e-03 | 1.680872e-01 | 8.404360e-01
R3 | crowbar | void |  | 16 | 320 |  | 0 | 0.000000e+00 | 1.680871e-01 | 1.680871e-01
R3 | crowbar | void |  | 16 | 320 |  | 1 | 1.666669e-03 | 1.680872e-01 | 3.361743e-01
R3 | crowbar | void |  | 16 | 320 |  | 2 | 3.333337e-03 | 1.680872e-01 | 5.042615e-01
R3 | crowbar | void |  | 16 | 320 |  | 3 | 5.000006e-03 | 1.680872e-01 | 6.723488e-01
R3 | crowbar | void |  | 16 | 320 |  | 4 | 6.666675e-03 | 1.680872e-01 | 8.404360e-01
R3 | crowbar | void |  | 17 | 320 |  | 0 | 0.000000e+00 | 1.680871e-01 | 1.680871e-01
R3 | crowbar | void |  | 17 | 320 |  | 1 | 1.666669e-03 | 1.680872e-01 | 3.361743e-01
R3 | crowbar | void |  | 17 | 320 |  | 2 | 3.333337e-03 | 1.680872e-01 | 5.042615e-01
R3 | crowbar | void |  | 17 | 320 |  | 3 | 5.000006e-03 | 1.680872e-01 | 6.723488e-01
R3 | crowbar | void |  | 17 | 320 |  | 4 | 6.666675e-03 | 1.680872e-01 | 8.404360e-01
R3 | crowbar | void |  | 15 | 500 |  | 0 | 0.000000e+00 | 1.680869e-01 | 1.680869e-01
R3 | crowbar | void |  | 15 | 500 |  | 1 | 1.666669e-03 | 1.680923e-01 | 3.361792e-01
R3 | crowbar | void |  | 15 | 500 |  | 2 | 3.333337e-03 | 1.680923e-01 | 5.042716e-01
R3 | crowbar | void |  | 15 | 500 |  | 3 | 5.000006e-03 | 1.680923e-01 | 6.723639e-01
R3 | crowbar | void |  | 15 | 500 |  | 4 | 6.666675e-03 | 1.680923e-01 | 8.404562e-01
R3 | crowbar | void |  | 16 | 500 |  | 0 | 0.000000e+00 | 1.680869e-01 | 1.680869e-01
R3 | crowbar | void |  | 16 | 500 |  | 1 | 1.666669e-03 | 1.680923e-01 | 3.361792e-01
R3 | crowbar | void |  | 16 | 500 |  | 2 | 3.333337e-03 | 1.680923e-01 | 5.042716e-01
R3 | crowbar | void |  | 16 | 500 |  | 3 | 5.000006e-03 | 1.680923e-01 | 6.723639e-01
R3 | crowbar | void |  | 16 | 500 |  | 4 | 6.666675e-03 | 1.680923e-01 | 8.404562e-01
R3 | crowbar | void |  | 17 | 500 |  | 0 | 0.000000e+00 | 1.680869e-01 | 1.680869e-01
R3 | crowbar | void |  | 17 | 500 |  | 1 | 1.666669e-03 | 1.680923e-01 | 3.361792e-01
R3 | crowbar | void |  | 17 | 500 |  | 2 | 3.333337e-03 | 1.680923e-01 | 5.042716e-01
R3 | crowbar | void |  | 17 | 500 |  | 3 | 5.000006e-03 | 1.680923e-01 | 6.723639e-01
R3 | crowbar | void |  | 17 | 500 |  | 4 | 6.666675e-03 | 1.680923e-01 | 8.404562e-01
R3 | crowbar | void |  | 15 | 900 |  | 0 | 0.000000e+00 | 1.680868e-01 | 1.680868e-01
R3 | crowbar | void |  | 15 | 900 |  | 1 | 1.666669e-03 | 1.681690e-01 | 3.362558e-01
R3 | crowbar | void |  | 15 | 900 |  | 2 | 3.333337e-03 | 1.681678e-01 | 5.044236e-01
R3 | crowbar | void |  | 15 | 900 |  | 3 | 5.000006e-03 | 1.681678e-01 | 6.725914e-01
R3 | crowbar | void |  | 15 | 900 |  | 4 | 6.666675e-03 | 1.681678e-01 | 8.407592e-01
R3 | crowbar | void |  | 15 | 900 |  | 5 | 8.333343e-03 | 1.681678e-01 | 1.008927e+00
R3 | crowbar | void |  | 16 | 900 |  | 0 | 0.000000e+00 | 1.680868e-01 | 1.680868e-01
R3 | crowbar | void |  | 16 | 900 |  | 1 | 1.666669e-03 | 1.681690e-01 | 3.362558e-01
R3 | crowbar | void |  | 16 | 900 |  | 2 | 3.333337e-03 | 1.681678e-01 | 5.044236e-01
R3 | crowbar | void |  | 16 | 900 |  | 3 | 5.000006e-03 | 1.681678e-01 | 6.725914e-01
R3 | crowbar | void |  | 16 | 900 |  | 4 | 6.666675e-03 | 1.681678e-01 | 8.407592e-01
R3 | crowbar | void |  | 16 | 900 |  | 5 | 8.333343e-03 | 1.681678e-01 | 1.008927e+00
R3 | crowbar | void |  | 17 | 900 |  | 0 | 0.000000e+00 | 1.680868e-01 | 1.680868e-01
R3 | crowbar | void |  | 17 | 900 |  | 1 | 1.666669e-03 | 1.681690e-01 | 3.362558e-01
R3 | crowbar | void |  | 17 | 900 |  | 2 | 3.333337e-03 | 1.681678e-01 | 5.044236e-01
R3 | crowbar | void |  | 17 | 900 |  | 3 | 5.000006e-03 | 1.681678e-01 | 6.725914e-01
R3 | crowbar | void |  | 17 | 900 |  | 4 | 6.666675e-03 | 1.681678e-01 | 8.407592e-01
R3 | crowbar | void |  | 17 | 900 |  | 5 | 8.333343e-03 | 1.681678e-01 | 1.008927e+00

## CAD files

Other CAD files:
docs/varcap-nodeanalysis-template-r0.15_TMD_layout.dxf
docs/varcap-nodeanalysis-template-r0_6_TMD_layout.dxf

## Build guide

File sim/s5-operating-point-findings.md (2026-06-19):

# Findings — S5: self-consistent operating point + dissipation

**Branch** `s5-operating-point` (off `main`, which carries the validated 789 pF tank + clamp + spark
verdicts). **Verdict:** **`OPERATING-POINT-STABLE`** — the pump↔tank↔clamp loop settles at a parked 15 kV
with **+12 % … +22 % margin** at the 6.0–6.5 mm fire gap, **V_fire 18.7–20.3 kV < 21 kV** (C1/C2 ceiling),
crowbar idle, across Q = 320/500/900. **+ `DIELECTRIC-Q-FLAG`** (garolite tanδ caps the AC ring Q, but the
v0.11 series-DC-hold topology is robust to it). The reach is now **pinned, not anchored**.

**What S5 retires:** the last *assumed* drive-side quantity — the absolute island fire voltage. S2 anchored
it at the 20 kV HV rail; S3 at a 17.2 kV real-gap strike and flagged "15.5 kV cold is tight." S5 lets the
**gap** set V_fire and solves the loop: V_fire is gap-set (18.7–20.3 kV at 6.0–6.5 mm), V_tank is clamp-set
(15 kV), and the tightness caveat is resolved by the recommended wider gap. With no consumer (TMD), this is
the **terminal drive-side characterization** — the metrics are hold power and cold-build efficiency, not a
delivered-power η.

**Scope / discipline:** consumer-only. The pump scale + island ledger come from the frozen `shuttle_core`
spark machinery (regression anchor z = 1.2033); the tank + two-tier clamp are the **unmodified**
`sim/resonator_sim.py`. S5 wraps a fixed-point solver around them. **Frozen empty-diff asserted**
(`shuttle_core.py` / `reference/` / `index.html` / `resonator_sim.py`). No DCCREG.

---

## §8 named checks (all PASS)

| # | check | result |
|---|---|---|
| 1 | f₀/Z₀ ring (guards 123 µH / 960 pF leaks) | f₀ = 635.5 kHz, Z₀ = 315 Ω ✓ |
| 2 | frozen empty-diff | clean (asserted at end) ✓ |
| 3 | regression `assert_ideal_identity` + anchor | z = 1.2033 ✓ |
| 4 | fixed-point convergence (held, reproducible) | v_peak = 15 kV, crowbar idle ✓ |
| 5 | ceiling guard V_fire < 21 kV | 18.7–20.3 kV ✓ |
| 6 | energy balance with losses < 0.1 % | E_inj = lossR + stored + crow + glow, rel 2.5e-4 ✓ |
| 7 | margin ≥ ~5 % at 6.0–6.5 mm | +12.2 % / +21.5 % ✓ |

## A1 — loop closure (V_fire set by the gap; tank settles at the clamp)

| gap | V_fire | E_M2 | V_cold | margin | <21 kV | v_peak | crowbar | held |
|---|---|---|---|---|---|---|---|---|
| 5.5 mm | 17.2 kV | 94 mJ | 15.4 kV | **+2.8 %** (tight) | yes | 14.95 kV | 0 | yes |
| **6.0 mm** | **18.7 kV** | 112 mJ | 16.8 kV | **+12.2 %** | yes | 14.95 kV | 0 | yes |
| **6.5 mm** | **20.3 kV** | 132 mJ | 18.2 kV | **+21.5 %** | yes | 14.95 kV | 0 | yes |

V_fire = 1.04 × (3 kV/mm × gap); E_M2 = η·½·Cx·V_fire² (η = 0.990); V_cold = √(2·E_M2/C_R) is the cold
single-kick tank peak the governor caps to 15 kV. **The fixed point is real:** the scale-invariant pump
boosts the island until the gap strikes (gap-set V_fire), and the governor parks the tank at 15 kV shedding
the surplus — no anchor needed. **The S3 "15.5 kV tight" caveat (5.5 mm, +2.8 %) is resolved by the 6.0–6.5 mm
gap (+12 … +22 %), with V_fire staying below the 21 kV C1/C2 ceiling at all gaps.**

## A2 — dissipation budget (settled point, 6.0 mm, Q = 500) — the new piece

| channel | power | note |
|---|---|---|
| **garolite dielectric** | **53.6 W** | tanδ ≈ 0.02 → Q_diel ≈ 50; **96 % of the ring loss** `[IR]` |
| copper R_ac | 2.2 W | Q_copper ≈ 1200 (coil-topology skin) `[IR]` |
| governor sink | 14.4 W | parked-hold shed (E_upstream / t_run) `[OC]` |
| arc (per fire × PRF) | 0.048 W | 0.08 mJ/fire × 600 Hz `[OC]` |
| windage | ≈ 0 | vacuum cavity — payoff of the vacuum design `[IR]` |
| glow/void | ≈ 0 | vacuum below Paschen minimum (S4-deferred) `[IR]` |
| bearing / mech | ~O(1 W) | order-of-magnitude only `[RH]` |

**`DIELECTRIC-Q-FLAG`.** Adding the dissipation budget (which every prior loss-free run lacked) surfaces a
real sensitivity: **garolite tanδ ≈ 0.02 → Q_diel ≈ 50**, so the dielectric is **96 %** of any AC ring loss
and would cap the working Q far below the swept 320–900 — a `DISSIPATION-LIMITED` result *for a parallel-ring
tank*. **But the v0.11 series-DC-hold topology (coil-topology / series-resonator, on `main`) is robust to it:**
the reach is a single impulsive kick (V_peak is Q-**independent** — set by energy, not Q), and at the DC hold
there is no AC voltage across C_R, so the dielectric AC loss → 0. The garolite dielectric therefore **does not
bind the operating point**; it only matters if the design relied on a high AC ring-Q. (Sweep tanδ if a high
ring-Q is ever needed; recommend a lower-loss septum — mica/ceramic — in that case.)

## A3 — operating point + efficiency

At 6.0 mm: V_fire = 18.7 kV (< 21 kV ✓), E_M2 = 112 mJ, **η_build = 0.795** (the 89 mJ that fills the tank to
15 kV ÷ the 112 mJ cold kick; the governor sheds the 23 mJ surplus). Across **Q = 320/500/900** the tank holds
v_peak ≈ 15 kV with the crowbar idle (the reach is Q-independent; only the ring loss scales). η_build is the
tank-charging step only; the whole-machine mechanical→tank efficiency is ≈ 0.45 (island-charging /
machine-energy-balance blocks, on `main`).

## A4 — build + hold dynamics

- **Cold build (M2 frame):** E_M2 = 112 mJ ≥ 89 mJ → **single-kick reach** (1 fire → 15 kV, 1.67 ms @ 600 Hz).
- **Cross-check (the multi-fire reality):** the series-DC-hold accumulation (coil-topology / series-resonator)
  builds in **~6 fires (≈ 10 ms)** — the M2-PARTIAL regime the island-charging co-sim pinned. S5's M2 frame is
  the optimistic single-kick bound; the realistic sourced delivery (~14 mJ/fire) gives the 6-fire build. Both
  reach 15 kV; the difference is the per-fire delivery model (full M2 dump vs rail-limited mid-collapse fire).
- **Parked hold:** the governor sheds the pump's over-delivery indefinitely; the crowbar stays idle (A1/A3
  held = yes at every gap and Q). **Hold power ≈ 14 W (series-DC-hold)** vs ≈ 70 W if the parallel ring had to
  be re-established each cycle — the series topology is the one that makes the hold cheap.

## Verdict + roadmap

**`OPERATING-POINT-STABLE`** — the reach is pinned: V_fire gap-set (18.7–20.3 kV, < 21 kV), V_tank clamp-set
(15 kV), margin +12 … +22 % at the recommended 6.0–6.5 mm gap, crowbar idle, energy balanced. The "15.5 kV
tight" caveat is retired. **`+ DIELECTRIC-Q-FLAG`** noted (non-binding for the series-DC-hold design; would
bind a parallel-ring tank). Remaining (TMD-gated, not S5 prerequisites): **S4** vacuum-gap glow / hemisphere
edge-flashover (geometry now in hand), then **thermal** (temperature rise from this dissipation budget). S5's
settled operating point is the locked anchor for both.

## Deliverables

`sim/s5_operating_point.py` (consumer-only fixed-point wrapper + A0–A4 + §8 checks) · this findings doc ·
`s5_operating_point.csv` · `s5_operating_margin.png` (margin vs gap) · `s5_dissipation_budget.png`
(per-channel power). Frozen empty-diff asserted. **Not merged.**

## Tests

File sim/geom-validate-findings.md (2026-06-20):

# Findings — GEOM-VALIDATE: island reconcile + A(θ) registration (the gate before the torque sim)

**Branch** `geom-validate` (off `geom-extract`). **Verdict:** **`PROFILES-VALIDATED`** — but only
**after two corrections this gate forced**, both of which the brief anticipated and the `geom-extract`
"hatch check 0.00 %" could not catch:

1. **The A(θ) magnitude was wrong.** The swept `A_max = 83 480 mm²` was **38 % of the true aligned
   overlap (221 080 mm²)** — an engine registration bug, not geometry. Diagnosed, fixed in the
   engine, and the exact **analytic** annular-sector profile re-emitted.
2. **The island is single-face**, decided **directly from the drawn axial cross-section** (one pickup
   electrode, nothing on the other face) — so the model's `Cx_max = 648 pF` is the **top** of the
   single-face band; the drawn representative is **~471 pF (~27 % lower)**. The frozen shuttle is
   re-derived; the impact is bounded and the full-sim is qualitatively robust.

With both resolved, the torque-resolved sim may consume the **corrected** `geom_profiles.csv` with
dC/dθ and the fire clock in one frame. The single-face-vs-redesign-to-two-face decision is **TMD's**
(flagged) and rescales only the **shuttle** term (≤15 %), not the **varicap** dC/dθ.

---

## Part A — the island reconcile (decided by the axial section, not back-inferred from C)

**A.1 — the direct evidence.** The drawn **axial** cross-section (Z-stack band, side elevation
x=radius / y=axial-Z) reads unambiguously:

| layer | axial Z | radial |
|---|---|---|
| **island bar** `ND7` | y ∈ [1158.2, 1162.2] | r75–350 |
| **gap** `CAP-Cx3` | y ∈ [1162.2, 1166.2] (**4.0 mm**) | — |
| **pickup** `ND3` | y ∈ [1166.2, 1170.2] | r58–350 |

**One pickup, on one face, across a 4.0 mm gap; nothing below the bar.** → the drawn island is
**SINGLE-FACE** (not two-face/differential). The `CAP-Cx3-GAP` ±x bands the parser also sees are the
two *diametric halves* of the annulus, **not** the face count — the face count is the axial flanking,
and it is one.

**A.2 — reconcile the 648 pF.** The brief's premise ("648 = 2 × 329 pF single-face-**air**, so
single-face halves to 324") is **retired on two counts**: single-face is confirmed (there is only one
face — no ×2), *and* the gap is **mica-loaded** (freeze v0.10: 3.0 mm + 0.3 mm mica/face, ε_r 5.4 →
2.5–3.1 mm effective), not 4.0 mm air (the air-at-4 mm reading was the drift-check error corrected in
`geom-extract`). The single-face nominal Cx_max:

| area basis | gap reading | Cx_max |
|---|---|---|
| drawn bars (148 k mm²) | 3.11 mm (mica added) | **421 pF** |
| drawn bars / solid (184 k) | mid | **~471–522 pF** |
| solid 6-sector (184 k) | 2.51 mm (mica replaces air) | **647 pF** ← the model's 648 |

So **single-face Cx_max ≈ 421–648 pF**, with the model's 648 at the **optimistic top** (solid-area +
mica-replaces-air). The drawn representative (discrete bars, balanced gap) is **~471 pF**.

**A.2 — frozen-shuttle re-derive** (the `island_charging` "real" scheme **run**, not edited):

| Cx_max pF | W_coll mJ | ΔW | E_fire mJ | ΔE | C_fire pF | V* kV |
|---|---|---|---|---|---|---|
| **648** (anchor) | 12.449 | +0.0 % | 13.951 | −0.0 % | 69.8 | 2.15 |
| ~471 (representative) | 11.078 | **−11 %** | 12.824 | **−8 %** | 64.1 | 2.72 |
| 421 (low) | 10.583 | −15 % | 12.412 | −11 % | 62.1 | 2.95 |
| 324 (brief air-halve) | 9.418 | −24 % | 11.436 | −18 % | 57.2 | 3.53 |

Across the realistic single-face band the shuttle impact is **W_coll −0…−15 %, E_fire −0…−11 %**; the
island still **fires at 20 kV < the 21 kV ceiling throughout** (V* — the pickup voltage — rises
2.15→2.95 kV but stays far under). **`ISLAND-SINGLE-FACE`**: the full-sim is **qualitatively robust**
(pumps / holds ~15 kV / fires under ceiling); the shuttle's W_coll/E_fire carry a bounded ≤15 %
downward revision pending the design call.

**A.3 design call (TMD, flagged to `dxf_flags.md`):** accept single-face (~471 pF, shuttle
re-derived) **or** add a second pickup face (differential) to realise 648 pF — a hardware change.
Either way the next DXF rev wants a per-face annotation.

## Part B — the A(θ) registration

**B.1 — θ-origin.** The drawn wedge occupancy (circle-fit spin axis):
- **C1 rotor and stator share the same 6-fold phase** (30° mod 60°, width 30°) over r95–387 →
  **aligned at θ=0 = electrical-0** (the "true C1" datum the firing-stations note pins). C1 A_max is
  at θ=0. ✓
- **C2 stator is interleaved** (phase 0° vs C1's 30°) → **C2 is anti-phase to C1 by design** (C2 min
  at θ=0, max at θ=30) — the correct 4-node doubler drive, **not** a registration error.

**B.2 — the magnitude ground truth (the catch).** The **analytic** annular-sector aligned overlap
(6 × 30° over r95–387, independent of any clip/grid engine) is **221 080 mm²**. The `geom-extract`
**swept** A_max was **83 480 mm² — 38 %** of that: a real **`A-MAGNITUDE-DRIFT`**. The
"hatch check 0.00 %" never caught it because it re-integrated the *same drawn polygon* with a second
method (engine self-consistency) against a 3 mm axial Z-strip, **not** the face-view overlap — exactly
the gap the brief flagged. **Root cause (diagnosed + fixed in the engine):** the spin centre was the
wedge-mass **centroid** (off the true axis by ~100 mm) and the 600-mm clustering **split a single
part-view** across cells → partial, mis-registered overlap and the wrong (stack-section) instance
winning. The engine now **circle-fits the spin axis** and **merges grid groups by spin centre**;
the residual is imperfect stroke-stitching (4 of 6 rotor wedges close cleanly), so — these being
**regular annular sectors** — the **exact analytic A(θ)** is adopted as the validated profile and
re-emitted.

**B.3 — phase sanity.** With the island collapse and the fire clock in one frame: at the **load**
station **SG3a (7.2°)** the island is at the high-C plateau (pickup) and C1 is at 76 % of max; at the
**fire** station **SG3b (16.05°)** the island is mid-collapse at **C_fire ≈ 70 pF** and C1 has fallen
to 46 % of max. Pickup at high C, fire at low C_fire, C1 monotone falling across the window → **phase
sane**.

**B.4 — `REGISTRATION-CONFIRMED`** (after the magnitude fix + analytic re-emit): θ-origin = electrical-0,
analytic A_max matched (the swept was the bug), phase physical.

## §-checks summary

| # | check | result |
|---|---|---|
| 1 | island axial face count | **1 pickup face** across 4.0 mm → single-face |
| 2 | island decision + re-derive | `ISLAND-SINGLE-FACE`; Cx_max ~471 pF (band 421–648); W_coll −11 %/E_fire −8 % at rep |
| 3 | C1/C2 max at θ=0 = electrical-0; occupancy | **C1 aligned at θ=0** ✓; C2 anti-phase by design |
| 4 | analytic A_max vs swept | analytic **221 080**; swept 83 480 was **38 %** → A-MAGNITUDE-DRIFT (fixed) |
| 5 | phase at SG3a/SG3b | pickup at plateau, fire mid-collapse, C1 falling → **sane** |
| 6 | gate verdict | **`PROFILES-VALIDATED`** (after 2 corrections) |

## Verdict + what it means

**`PROFILES-VALIDATED`** — the island is resolved (**single-face**, shuttle re-derived) **and** the
registration is **confirmed** — but this gate **earned its place**: it caught that the `geom-extract`
A(θ) **magnitudes were 2.6× wrong** (an engine registration bug the self-consistent hatch check
structurally could not see) and that the island is **single-face** (Cx_max 648 → ~471 pF). The
torque-resolved sim consumes the **corrected, analytic** `geom_profiles.csv`: dC/dθ and the fire clock
are provably co-registered (C1 max at electrical-0, exact 221 080 mm² magnitude), so the
`½V²·dC/dθ` term the independent guard is built on is sound. The single-face-vs-two-face **design
call is TMD's** (flagged); it rescales only the **shuttle** term (W_coll/E_fire, ≤15 %), not the
varicap term.

## Deliverables

`sim/geom_validate.py` (island axial-section extractor + conditional frozen-shuttle re-derive +
registration/phase checks; reuses + fixes the `geom-extract` engine — circle-fit spin axis,
spin-centre group merge — and adds the exact analytic annular-sector overlap) · this findings doc ·
**re-emitted `geom_profiles.csv`** (analytic A(θ), method-tagged, registration-correct: C1 A_max
221 080 @ 0°, C2 @ 30°) · `dxf_flags.md` updated (island single-face per-face annotation; the A(θ)
magnitude fix). r0.15 DXF + frozen solvers read-only, empty-diff asserted. **Not merged.**

> **Note on the shared engine.** `sim/geom_extract.py` carries the spin-centre fix (the
> A-MAGNITUDE-DRIFT root cause) and a softened C1/C2 endpoint note (the absolute C_max is gated on
> the **axial Z-gap**, which is not in the radial view — informational, like the fixed-cap electrode
> areas; the A(θ) **shape** is what's validated). `geom_extract` still returns `GEOMETRY-CONSISTENT`.
> `geom_validate` is the authoritative profile emitter (run it last / with `geom_extract`); the
> validated `geom_profiles.csv` is the **analytic** one.

### Roadmap

`PROFILES-VALIDATED` → the **torque-resolved angular sim** (the next brief) runs the independent
`∮[½V²·dC/dθ + ½i²·dL/dθ]·ω dt` guard and the real `½i²·dL/dθ` output on these co-registered profiles
(the varicap term is geometric now; the Cem L(θ) still awaits the concentric-pole drawing punch-list,
carried `[IR]` until then). TMD settles the island single-face value (accept ~471 pF or redesign to
two-face 648). Then **v0.11** freezes with r0.15 as the geometric authority and the validated profiles
as the locked inputs.

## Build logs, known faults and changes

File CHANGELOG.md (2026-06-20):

# Changelog

Format adapted from [Keep a Changelog](https://keepachangelog.com/). Git holds the authoritative history; this file is the human-readable audit trail. The discipline is inherited from the DCCREG programme conventions; the physics is mainstream (no DCCREG theory).

## [Unreleased]

### Frozen
- **Design freeze v0.10 (temporary, tag `freeze-v0.10`) — disc 8→12 mm → C_R 960→789 pF** — temporary github snapshot of the validated v0.10 geometry + cap set (`docs/varcap-design-freeze-v0.10.md`). The C_R septum disc went 8→12 mm garolite, pinning **C_R 960→789 pF** at the r387 electrode (f₀ 637 kHz, Z₀ 316 Ω). This **lowers the single-kick reach floor (½·C_R·V²) 108→89 mJ**, **improves the M2 island-dump match η 96→99 %** (648 pF island ≈ 789 pF tank), and **widens the fire window 18.6–21 → 16.6–21 kV**. C1/C2 (r387, 16–280 pF), Cx (648 pF), Ca/Cb (309 pF) held; pump z 1.307, galvanic ceiling 1.334, ledger clean — all unchanged. **Six spark gaps placed** (SG1/SG2 return, SG3a/SG4a load, SG3b/SG4b fire — 12 mm W-Cu spheres). **Open / named TODO:** BS3/BS4 backstops (19°/49°, 0.6×strike, outer ~r350–380) + the `varcap-nodeanalysis-template-r0_10_TMD_layout.dxf` (not yet drafted), the S3 spark tier, and the S2 reach re-confirm at 789 pF. Frozen solvers (`shuttle_core.py`, `reference/doubler_core.py`) + `index.html` byte-identical (empty diff asserted); documentation + DXF only. Temporary freeze — **not merged**.

### Investigated
- **DESIGN-SYNTH — a constrained dimension-chooser (free dimensions, invariant rules) → `SYNTH-FEASIBLE` (branch `design-synth` off `torque-sim`)** — the standing bridge between *intent* and *geometry*: Claude Code may choose **every** dimension (plate radii, gaps, cap values, rpm, staging, motor geometry), but each candidate is checked against a fixed battery of **invariants** — the validated derivations + rules-of-thumb + conservation — so flexibility can only move within the feasible region the rules define; it can never quietly override a derivation. New **`sim/design_synth.py`**, `sim/design-synth-findings.md`, `synth_design.csv`, `synth_compliance.csv`, `synth_feasible.png`. Frozen empty-diff asserted; **not merged** (synthesized designs feed the DXF/deck only on TMD approval). **Principle realized:** the synthesizer **calls** the frozen solvers (`doubler_core` z/η, frozen `shuttle_core` W_coll) per candidate — never re-derives/fits/overrides — and z/η being **scale-free** (ratios only) are cached by the normalized ratio tuple. **The invariant battery (I1–I10), reconstructed from the campaign's established results** (no separate numbered-rules doc exists in-repo): I1 conservation(real, +5% trip) · I2 frozen-solver authority · I3 scale-free z∈[1.20,1.45] · I4 insulate-first(gap V_bd, septum, split-coil) · I5 tax/staging(η≥0.15) · I6 parasitic floor(C_par≥20 pF) · I7 motor matched(out≤net, f_res=PRF, f₀-spectator) · I8 DC-trapped tank · I9 mechanical(rim<200 m/s, supercritical, vac≤10 Pa) · I10 shuttle integrity(strike<21 kV ceiling). **Checks:** frozen solvers called per candidate; **regression anchor REPRODUCES** (established ~1000 mm/15 kV → C1_max **280 pF** exact, z **1.334**, η **0.386**, feasible on all 10, least-slack I10); **I1 conservation closes (resid ≤1.3×10⁻¹⁶) AND the +5% self-test trips** (non-tautological — the discriminator is the trip, not the magnitude, as in torque-sim). **Synthesized designs (Claude Code chose; the rules held), each with a DISTINCT binding constraint found by perturbing the objective toward improvement:** **min-diameter** → dia **500 mm** (z 1.272, η 0.441) **bound by I3** (shrinking to dia 400 collapses the modulation, z<1.20); **max-η** → dia 700 mm, **η 0.526 bound by I3** (higher η ⇒ lower modulation ⇒ z hits the 1.20 floor); **max-rpm** → **6000 rpm** (rim 157 m/s) **bound by I9** (9000 rpm would exceed the 200 m/s rim limit). **Infeasible-goal probe** (demand dia≤300 mm @15 kV) → **`SYNTH-INFEASIBLE`** (0/6 feasible) **with the named blocker I3** — at r_out 150 the C_max (62 pF) nears the 20 pF stray floor, the modulation collapses, **z→1.000 (no pumping)**; the goal is impossible without relaxing a stated rule (higher-z family, smaller stray, or a lower z) and the tool says which. **Verdict `SYNTH-FEASIBLE`** — the flexibility lives in the dimensions, the discipline in the invariants, and the frozen solvers keep the two from trading places; the **binding constraint** per objective is the actionable output (I3 for size/efficiency, I9 for speed). *(Base-branch note: the brief's `design-optimize` base does not exist in-repo; branched off `torque-sim` and reconstructed the rules — the synthesizer drops onto a formal rules block unchanged if one is built first.)* Frozen empty-diff; **not merged**.
- **TORQUE-SIM — the torque-resolved angular machine on validated profiles → `GUARD-CLOSES + SELF-SPIN-INDETERMINATE` (branch `torque-sim` off `geom-validate`)** — the simulation the whole arc built toward: with `PROFILES-VALIDATED` (co-registered analytic A(θ), C1 max at electrical-0, fire stations exact), time-step the rotor over θ, compute the **instantaneous torques** from the geometry, and build the **genuinely independent conservation guard** — retiring the **1.2×10⁻¹⁶ identity** the energy-bookkeeping full-sim could not escape. New **`sim/torque_sim.py`**, `sim/torque-sim-findings.md`, `torque_partition.csv`, `torque_phase.csv`, `torque_phase.png`. Frozen solvers read-only (empty-diff asserted); the shuttle re-derive **runs** the frozen module. **No new energy.** **The two full-sim defects fixed for the dominant terms:** (1) **independent guard, for real** — `E_belt_in = ∮[T_varicap + T_shuttle + T_drag]·dθ` (a θ-integral of instantaneous torques, the SOURCE) vs **separately accumulated** loss models (the doubler C-C tax from equalization, reach `η_fire·E_fire`, transfer loss, governor-shed, drag — the DEST, **not** derived from the torque integrals); (2) **output as a computed torque** `T_cem = ½i²·dL/dθ`, not `P_motor − losses`. **Gate 0:** z **1.334**, η **0.386** (frozen doubler), **W_mech 15.941 mJ reconstructed as ∮T_varicap·dθ** (varicap gap back-solved g≈6.99 mm) and **W_coll 11.078 mJ as ∮T_shuttle·dθ** (single-face). **Stage B headline:** the guard closes (E_belt_in = E_diss = 28.874 mJ/cycle, resid **9.6×10⁻¹⁶**) AND the **mandatory +5% non-tautology self-test TRIPS** every torque term (varicap → **2.7%**, shuttle → **1.9%** — moving the residual ~3 orders) — which the r0.2 identity, by construction, **could not do**. *The discriminator is the trip test, not the baseline magnitude* (the baseline is tighter than the brief's nominal ~1e-6 because the varicap+shuttle energies are analytic, not stiff-ODE; the methodological point — **a guard that can fail** — is achieved). **Stage C:** `T_cem = ½i²dL/dθ` with switched-reluctance phasing (energised on rising-L so the average is net-motoring, not zero); pump-limited I_peak ~105 mA, **f₀ spectator → reach holds 14.95 kV**, island fires **20 kV < 21 kV**; **computed output torque 1.67–6.70 mN·m** across the `[IR]` L(θ) band; the guard **still closes** (9.6×10⁻¹⁶) with the Cem leg. **BALANCE:** output 1.67–6.70 vs stator drag **1.68 mN·m** → margin **−0.01…+5.0** → **the band straddles zero**. **Stage D:** four-destination partition (storage 88.76 mJ / computed output ~1.4 mJ / dissipation 28.87 mJ; tax 9.79, reach 12.64, transfer 0.19, gov-shed 4.41, drag 1.85) + **the angular record** (the long-pending phase-by-phase fire sequence on the **simulated** station angles: SG3a 7.2° load C1 217 pF → SG3b 16.05° fire C_fire 64 pF, SG4a 37.2°, SG4b 46.05°). **Stage E:** the geometric (varicap+shuttle) guard is rock-solid across every sweep (~10⁻¹⁶); the only `[IR]` lever is the Cem L(θ) depth (→ the output band). **Verdict `GUARD-CLOSES + SELF-SPIN-INDETERMINATE`** (the expected landing): the energy guard is **finally real** for the dominant terms (closes + can fail), the output is a **computed reluctance torque**, and the self-spin **sign** is gated entirely on the **concentric-pole drawing** (the `[IR]` L(θ) band straddles the drag) — a bounded drafting task, not a modelling unknown. Robust/geometric: pump+shuttle accounting, 15 kV reach under the Cem spectator, island under ceiling, drawn fire clock. Frozen empty-diff; **not merged**.
- **GEOM-VALIDATE — island reconcile + A(θ) registration (the gate before the torque sim) → `PROFILES-VALIDATED` (after 2 gate-forced corrections) (branch `geom-validate` off `geom-extract`)** — the last check before the `geom-extract` profiles become load-bearing for the torque-resolved sim. New **`sim/geom_validate.py`**, `sim/geom-validate-findings.md`, **re-emitted `geom_profiles.csv`** (analytic, registration-correct), `dxf_flags.md` updated. DXF + frozen solvers read-only (empty-diff asserted); the conditional re-derive **runs** the frozen shuttle, does not edit it. **PART A — island reconcile (decided by the AXIAL section, not back-inferred from C):** the drawn Z-stack cross-section shows the island bar (ND7, Z[1158.2,1162.2]) with **ONE pickup face** (ND3, above, across the **4.0 mm** gap) and **nothing below** → the island is **SINGLE-FACE**, not two-face/differential. The brief's premise ("648 = 2×329 single-face-air → halve to 324") is **retired on two counts**: single-face confirmed (no ×2) AND the gap is mica-loaded (not 4 mm air, the drift-check error already corrected). Single-face Cx_max ≈ **421–648 pF** (drawn bars .. solid-area; the model's 648 is the optimistic TOP), representative **~471 pF (~27 % lower)**. Frozen-shuttle re-derive across the band: **W_coll −0…−15 %, E_fire −0…−11 %** (−11 %/−8 % at ~471 pF); island still **fires at 20 kV < 21 kV ceiling throughout** → **`ISLAND-SINGLE-FACE`**, full-sim **qualitatively robust** (pumps/holds/under-ceiling), shuttle term carries a bounded ≤15 % downward revision; the accept-single-face-vs-redesign-to-two-face call is **TMD's** (flagged). **PART B — A(θ) registration (the catch the hatch check couldn't make):** the **analytic** annular-sector aligned overlap (6×30° over r95–387, engine-independent) is **221 080 mm²**, but the `geom-extract` **swept** A_max was **83 480 mm² — 38 %** → a real **`A-MAGNITUDE-DRIFT`** (the "hatch check 0.00 %" only proved engine self-consistency against a 3 mm axial Z-strip, exactly as the brief warned). **Root cause diagnosed + fixed in the engine:** the spin centre was the wedge-mass **centroid** (off-axis ~100 mm) and the 600 mm clustering **split a part-view** → partial/mis-registered overlap; the engine now **circle-fits the spin axis** + **merges groups by spin centre**, and the **exact analytic A(θ)** is adopted (regular sectors) and re-emitted. **C1 rotor & stator share the same 6-fold phase → aligned at θ=0 = electrical-0** ("true C1" datum); **C2 interleaved → anti-phase by design** (C2 min at θ=0, max at 30 — correct doubler, not an error). **Phase sane:** load SG3a (7.2°) at the island plateau / C1 76 % of max; fire SG3b (16.05°) mid-collapse C_fire≈70 pF / C1 46 % → **`REGISTRATION-CONFIRMED`** after the fix. **Verdict `PROFILES-VALIDATED`** — island resolved + registration confirmed → the torque sim consumes the **corrected** `geom_profiles.csv` (dC/dθ and the fire clock co-registered, the `½V²·dC/dθ` term sound); the gate **earned its place** by catching the 2.6× magnitude bug and the single-face island. *(Shared-engine note: `geom_extract.py` carries the spin-centre fix + a softened C1/C2 endpoint — the absolute C_max is gated on the axial Z-gap, not in the radial view, so informational like the fixed-cap areas; the A(θ) **shape** is validated; `geom_extract` still returns `GEOMETRY-CONSISTENT`; `geom_validate` is the authoritative analytic profile emitter.)* Frozen/DXF read-only; **not merged**.
- **GEOM-EXTRACT — r0.15 DXF → overlap(θ)/gap profiles + fire stations → `GEOMETRY-CONSISTENT` (branch `geom-extract` off `topology-recon-r0_13`)** — a **read-only `ezdxf` parser** that turns the fully-dimensioned r0.15 drawing into the **angle-profiles the torque-resolved sim consumes**: per part it emits the geometric **overlap-vs-angle `A(θ)`** + the **gap `g`** + the **fire-station angles**, validated against the drawn hatches and checked against the model's assumed values. **Purely geometric by design** (emits `A(θ)`/g/stations/dims, NOT C/L — the sim applies ε/μ/fringing; a nominal C is computed for the drift check only). New **`sim/geom_extract.py`**, `sim/geom-extract-findings.md`, `geom_profiles.csv` (θ-sampled `A(θ)` for C1/C2/Cx3/Cx4), `geom_stations.csv`, `geom_fixed.csv`, `geom_profiles.png`. DXF + frozen read-only (empty-diff asserted). **Coordinate reality resolved:** r0.15 lays each part 1:1 in its own **translated view-frame** (not concentric about the datum), datum/12-sector-grid/ref-radii as a (0,0) overlay — "true-scale selection" = pick a part's own-view instance (extent ∈[R25,R500] about its spin centre), reject the +y schematic glyphs + the r≈5009 replica; **stator** wedges are closed polylines but **rotor** wedges are **open arc+radial strokes** (stitched into closed loops). **Parser-correctness PASS:** grid area-engine re-integrates each drawn hatch to **0.0–0.6 %**, analytic 6×30° annulus to **3.2 %** → not `PARSER-INVALID`. **CONSISTENT:** **C1/C2** plate sweep `A(θ)` **0→83 480 mm²** (model C_min 16 pF = **fringe floor**, not geometric; implied axial gap **2.64 mm**); **all four freeze fire-stations EXACT** (drawn **SG3a 7.2 / SG3b 16.1 / SG4a 37.2 / SG4b 46.0°** vs **7.2/16.05/37.2/46.05**, <0.1°; SGs drawn 6-fold, station = angle mod 60°); **Cx3/Cx4 reconcile** under the **design mica gap** (3.0 mm + 0.3 mm mica/face, ε_r 5.4 → ~2.5 mm eff → ~520–540 pF vs model 648). **Correction (superseding the first-pass `GEOMETRY-DRIFTS`):** the Cx "factor 2 / two-face island" was a **drift-check error in this parser** (it modelled the 4.0 mm drawn *envelope* as **air**), **not** a hardware drift and **not** a full-circle-vs-sector mistake (the parser already measured the *sectored* 148 k mm² overlap, ~0.4 of the full annulus — a full-circle grab would have *overshot* ~820 pF). Calibration confirms the model's method exactly: **G1 88 pF = 6-sector r75–232 / 7.6 mm air**, and **648 pF = 6-sector r75–350 / 2.51 mm-eff**; the factor 2 decomposes exactly (×1.97) into dielectric/gap (×1.59) + bar-fill (×1.24). **One soft residual (flagged, deferred to the sim — not a drift):** the model's 648 pF idealizes the island as a **solid** 6-sector plateau; the drawn **discrete bars** realize **~81 %** of that area → real Cx_max ≈ **525 pF (~19 % below 648)**, closed by inter-bar **fringing** (the sim's job) or a small model trim. **Scope / drawing punch-list (NOT drifts):** Ca/Cb/C_R electrode **area** (`ND*-…-ELECTRODE` layers carry only schematic glyphs; gaps 1.0/12.0 mm confirmed) + **L_A/L_B Cem pole sweep** (motor is a distribution schematic, not concentric poles) — need dedicated part-view/attributed layers next rev. **Bottom line:** the S5–full-sim results riding on **station timing, plate geometry, and the island cap** are on hardware-matching numbers (island within the sim's fringing tolerance). Frozen/DXF read-only; **not merged**.
- **FULL-SIM — the complete coupled machine on the locked r0.15 graph (real shuttle + real Cems) → `FULL-CLOSES` (thin, vacuum-gated) (branch `full-sim-coupled` off `topology-recon-r0_13`)** — the first **true full-machine** simulation: the emergent spark-gap doubler (S8 r0.2) + the **real flying-bucket shuttle** (nodes 7/8, retiring the `W_COLL` constant) + the resonator fire-ring + the **12 real Cem branches** (L_A/C_AR, L_B/C_BR, retiring the `P_CORE`/`P_MOTOR` stub) + quasi-static contra-rotation — **one model, all components real, on the confirmed graph**, superseding the stitched S5–S8 stack. New **`sim/full_sim_coupled.py`** (the full multi-rate integrator), `sim/full-sim-findings.md`, `full_sim_partition.csv`, `full_sim_cem_branches.csv`, `full_sim_partition.png`. **No new energy** — the belt sources every watt; a non-closing ledger is a bug, not a discovery. **The three r0.2 defects are fixed:** (1) the **tautological guard** is replaced by the **independent mechanical torque integral** `E_belt_in = ∮T_retard·ω dt = W_mech(½∮V²dC) + W_coll(collapse) + E_drag`, checked against destinations tallied from the *electrical/loss* models — closes to **1.2×10⁻¹⁶** (a real check; it caught and forced removal of an arc double-count this build); (2) **output emerges** = `P_motor − copper(i²R) − core(flux)` = **+0.91 W** (sign positive, a result, not pinned 0); (3) **real circulation** (∫|P_internal|, p-p storage) = **22.3 mJ**, retiring the `½·440nF·(3kV)²` placeholder (tracks cap_scale 11↔45 mJ). **Stage A Gate 0:** the stub limit reproduces **S8 r0.2 exactly** (z **1.334** + η **0.3860** re-derived emergently from frozen `doubler_core`/G3 + the `½∮V²dC` decomp; dissipation **56.08 W**, storage **88.76 mJ**, output 0). **Stage B:** **W_coll EMERGES = 12.4489 mJ** (matches the frozen `shuttle_core` anchor < 0.05 mJ — the constant is retired to a per-cycle result), E_fire 13.95 mJ, island fires at **20 kV < 21 kV ceiling**. **Stage C:** the 12 branches are **PRF-resonant** (f_res **299.9 Hz** = PRF_branch) and **high-Z spectators at f₀** (|Z| 2.56 MΩ = ×8112 Z₀ → reach holds, not detuned); **emergent** I_peak **107 mA** (N·I **114 A-t** « 1650), B **72 mT**, copper **1.40 W**, **core(flux/Steinmetz) 0.48 W — NOT the fixed 15 W stub**, output **0.91 W**. **Stage D:** four-destination partition — storage 88.76 mJ / circulation 22.3 mJ / **output 0.91 W** / **dissipation 16.7 W (the real floor — far below the 56 W stub and the 138 W artifact)** because the real flux-core is cheap; guard 1.2×10⁻¹⁶. **BALANCE (the S7 question, now MEASURED on the real branches):** output 0.91 W vs stator **mechanical** drag 0.53 W → **margin +0.38 W at 1 Pa**. **Stage E:** the close is **entirely vacuum-gated** — +0.38 W (1 Pa), +0.13 W (10 Pa), **−2.4 W (100 Pa)**; the septum DOF (garolite→mica) does **not** move the output (ring-side, not motor-side); cap_scale moves only the reactive circulation. **Verdict `FULL-CLOSES` — but thin and conditional, stated plainly:** the machine pumps, holds 15 kV under the real load, and contra-rotates with positive emergent output that clears the stator drag **only in a clean cavity** (≤10 Pa); the dominant lever is **windage/vacuum** (not the iron — S7's feared 15 W core is really 0.48 W), and the +0.38 W rests on the **[IR] resonant-branch model** (Q_CEM=30) so a lower Q/higher copper erases it. **What's robust:** pump works, reach holds, W_coll 12.449 mJ, Cems are f₀-spectators, real floor 16.7 W, guard 10⁻¹⁶. The headline is not "free spin" — it's that the wall is windage, and a thin contra-rotation balance closes **iff the cavity is pumped down**. **Precondition flag:** branched off `topology-recon-r0_13` (carries the DXF-sourced edge list + `main`'s S8) since the recon isn't merged to `main` yet — **merge it for v0.11** so the edge list is the topology of record there. Frozen solvers (`doubler_core.py`, `shuttle_core.py`, `resonator_sim.py`) byte-identical (empty-diff asserted); **not merged**.
- **Topology recon r0.2 — net-for-net vs the committed r0.15 EE schematic → `TOPOLOGY-CONFIRMED` (branch `topology-recon-r0_13` off `main`)** — the **r0.15 EE schematic is now committed** (`docs/varcap-nodeanalysis-template-r0.15_TMD_layout.dxf`), so the net-for-net wiring check r0.1/r0.2 couldn't run (no schematic in the repo → `TOPOLOGY-INCOMPLETE`) finally proceeds. Rewrote **`sim/topology_recon.py`** r0.2 (the r0.15 **net-tracer**: schematic parse + wire-graph by endpoint coincidence + symmetry/mislabel audit + the `[?]`/motor/split-resonator confirmation), `sim/topology-recon-findings.md` r0.2, `topology_edge_list.csv` (re-stamped **DXF-sourced r0.15** — the manifest of record), `dxf_flags.md`. DXF + frozen read-only (empty-diff asserted). **Completeness RESOLVED:** the schematic carries the 00-CIRCUIT-SCHEMATIC + SCHEMATIC layers (drawn wiring), the motor (MECH-CEMS/COIL-CEMS/quadricores + 10 INSERT arrays), the split-resonator nodes (ND9/10), and **all 22 node labels** — the ND9/10 + 24-component motor that r0.1/r0.2 flagged as undrawn are now present. **Checks:** Stage B symmetry **10/11 pairs mirror exactly**, the **one asymmetry ND7↔ND8** (ND8 ~157 off its mirror) flagged to `dxf_flags.md` as a **label-position** check — the connectivity (Cx4 8-2, SG4a 4-8, SG4b 8-2, BS4 2-8) is coherent, so a likely drafting-layout artifact, **not a wrong edge**; Stage C the four `[?]` confirmed **against the drawing** (agrees with freeze §5 + deck: SG3a 1-7, SG4a 4-8, BS3 3-7, BS4 2-8, backstops blocking the reverse of the 7→3/8→2 fire); Stage D the **wire-graph net-traces** the spatially-separable edges exactly to the deck (**C_R→9-10** with its label between ND9/ND10, SG1→2-5, SG2→3-6, C2→4-6), and the **motor is two symmetric banks of 6** (A 11-16 near ND1/2, B 17-22 near ND3/4) matching the manifest. **No edge disagrees.** **Method note (honest):** the dense doubler/commutation symbols are raw geometry (lines/circles/splines, not blocks-with-terminals), so an *isolated per-symbol* terminal trace isn't robustly extractable — those edges are confirmed by node-layout + symmetry + freeze §5 + the traced subset (not contradicted) — a tooling caveat, not a discrepancy. **Verdict `TOPOLOGY-CONFIRMED`** (+ one cosmetic ND7/8 DXF flag): the full 42-component graph is drawn and consistent with deck v0.3 everywhere checkable → **the graph LOCKS** for the shuttle/Cem model upgrade (retire the W_COLL constant + the Cem P_CORE/P_MOTOR stubs) and **v0.11** (which freezes sim+DXF+`.cir`+doc with r0.15 as the geometric authority of record and the DXF-sourced edge list as the manifest). Deck v0.3 stands confirmed — no v0.4 correction needed (the only flag is a DXF cosmetic). Frozen/DXF read-only; **not merged**. *(Supersedes the r0.2 precondition-unmet result now that r0.15 is committed.)*
- **Topology recon r0.2 — net-for-net vs the r0_13 EE schematic → `TOPOLOGY-INCOMPLETE` (gating precondition unmet) (branch `topology-recon-r0_13` off `main`)** — r0.2 was gated on the **r0_13 EE schematic being committed** so its drawn nets could be traced + diffed net-for-net against deck v0.3. **r0_13 is NOT in the repo:** an exhaustive scan of *every* `.dxf` blob across *all* git history finds only three files (r0_6, r0.1, r0.2), **all radial-layout templates** (no ND9/10, no motor, no schematic/wire layer, 0 INSERTs) → there are **no drawn nets to trace**, so the net-for-net diff **cannot run**. Rewrote **`sim/topology_recon.py`** r0.2 (exhaustive cross-history DXF inventory + a gate that **auto-detects** a real schematic by ND9/10+motor and proceeds to the net-trace when one appears; **refuses to fabricate a trace of a non-existent file**), `sim/topology-recon-findings.md` r0.2, `dxf_flags.md` (the drawing punch-list), `topology_edge_list.csv` (re-affirmed, **source still freeze §5 + physics, NOT DXF**). DXF + frozen read-only (empty-diff asserted). **Escalation:** this is the **second brief** (r0_15, then r0_13) gated on a schematic DXF that **has never entered the repo** — the recurring blocker is the **schematic itself, not the deck**. The r0.1 result stands and is re-affirmed: the 42-component manifest reconciles from freeze §5 + Block-D + physics, A/B symmetry exact, the four `[?]` resolved (SG3a 1-7, SG4a 4-8, BS3 3-7, BS4 2-8 — backstops block the *reverse* of the 7→3 / 8→2 fire) — but these remain **freeze-sourced, not drawn-net-confirmed**, and the split resonator (ND9/10) + 24 motor branches are **undrawn in any DXF** (representation gap, not a deck error — no edge disagrees). **Verdict `TOPOLOGY-INCOMPLETE`:** the graph cannot be marked DXF-sourced and v0.11 cannot freeze against r0_13 until the schematic is actually committed; `dxf_flags.md` specifies what it must contain (drawn nets, ND9/10, the 24 motor components, the four `[?]` as nets). The deck's connectivity is trustworthy *where checkable* (the 18-component core + the shuttle path), so the shuttle/Cem model upgrade may proceed on that locked sub-graph, but the net-for-net confirmation + the v0.11 freeze wait on committing the EE-schematic DXF. **Action:** commit r0_13, re-run the tracer (it auto-detects + proceeds). Frozen/DXF read-only; **not merged**.
- **S8 — unified coupled model + four-destination energy ledger (does the nest beat the sum of its parts?) → `SYNERGY-GENERIC` (branch `s8-unified-coupled-ledger` off `main`)** — replaces the *stitched* S5–S7 budget (each box solved in isolation, then added) with **one coupled electromechanical model of the whole nest** (split resonator + varicap pump + Cem branches + contra-rotation), instrumented to report energy **by destination per cycle** (storage / circulation / output / dissipation) and answer the question the piecewise method structurally can't: is coupled `E_diss/E_in` below the stitched prediction, and which coupling carries it? **Framing honored — no new energy** (the belt sources every watt; a synergy = lower dissipation *fraction*, not gain). New **`sim/s8_unified_coupled.py`** (custom Python integrator — SPICE ruled out, the shuttle is ngspice-blocked; the fast f₀ ring transient at f₀ resolution with the dielectric as a genuine shunt conductance, the slow Cem/mechanical at PRF, mechanical quasi-static; **consumer of frozen z/reach**, empty-diff asserted), `sim/s8-unified-coupled-findings.md`, `s8_energy_partition.csv`, plots (`s8_partition.png`, `s8_diss_frac_sweep.png`, `s8_conservation_guard.png`). **The hard conservation guard earned its keep:** the first build double-counted the Cem electrical input + mis-booked the C_R chain → the guard fired (`CONSERVATION-VIOLATED`, residual 0.24); rebuilt to one consistent energy chain (belt → pump+collapse → C_R chain → heat; belt → Cems → core/copper/output), after which the **fire-ring ODE closes to 2.3×10⁻⁶** at every tuning point. **§5 checks all pass:** Gate 0 (couplings-off reproduces z **1.2033** / f₀ **637 kHz** / reach **14.95 kV** before any coupling); baseline partition (storage 88.76 mJ, circulation ~1980 mJ diagnostic, **output ~0 W** — motor core-loss-limited per S7, **dissipation 56.1 W**); Stage C each coupling moves `E_diss/E_in` by **+0.0000**; Stage D the fraction & the 56 W floor are **flat across every DOF** (septum garolite↔mica, k 0/0.3/0.6, fire-phase ±15°, cap-scale 0.5/2×) with no sub-stitched minimum (the U-tube/local-wrong probe is negative); Stage E the parametric channel is **dormant** (rotor 300 Hz vs 2·f₀ 1.27 MHz, ~10⁻⁴). **Concrete payoff — the 53 W phantom debunked:** the stitched garolite dielectric (~53 W = 88 mJ/cycle) is **physically impossible** (it exceeds the whole ~28 mJ/cycle C_R chain); the coupled value is **0.033 W** (a 1584× over-estimate) because the **series-DC-hold waveform duty-cycles the AC ring to ~0.03 %** (the coil-topology/S5 topology, NOT a coupling; tanδ is heat, not circulation). So the **septum material is not load-bearing** at the operating point (the "5× tank-loss swing" applied only to the continuous-ring phantom). **Verdict `SYNERGY-GENERIC`:** the nest is the sum of its parts, the floor is real, tuning only redistributes within it — the conservation-tuning question is **closed** and the stitched budget **vindicated**; the only levers are the floor ones (lamination/flux → core, vacuum → windage), exactly where S7 points. Frozen empty-diff asserted; **not merged**.
- **S7 — expanded-circuit operating point (FIRST, gating) + estimated drag budget & spin-up balance → `OPPOINT-HOLDS` + `BALANCE-FAILS` [EST] (branch `s7-expanded-oppoint` off `main`)** — re-establishes the electrical operating point on the *expanded* circuit (varcap.cir v0.2: split resonator L_R1+C_R+L_R2 + the 12 Cems as an explicit load across Ca/Cb), then folds in a drag/spin-up balance. **Hybrid method** (the prior xsim work found the nonlinear flying-bucket shuttle is **ngspice-BLOCKED**, but the galvanic core recovers z and the linear expanded elements are ngspice's strength): **ngspice** for the galvanic regression + the new linear physics (split-resonator f₀, Cem-branch impedance), the **frozen `resonator_sim`** for the unchanged reach, energy-budget + coil-topology for the node transients & pump→motor power, and coarse `ρω³R⁵`-class models for Phase-2 drag (every figure tagged ESTIMATE). New **`sim/s7_expanded_oppoint.py`** + `sim/s7-oppoint-drag-findings.md`, `s7_oppoint_drag.csv`, plots (`s7_phase1_oppoint.png`, `s7_drag_balance.png`); **frozen empty-diff asserted** (doubler_core/shuttle_core/resonator_sim/reference). **PHASE 1 (gating) → `OPPOINT-HOLDS`:** §3 checks all pass — 1A the runnable galvanic deck recovers **z = 1.2042** vs the frozen 1.2033 (Δ < 0.03) *before* enabling new elements; 1B the split (two L_R/2, k=0.3 aiding, sized) preserves **L_total 79.0 µH / f₀ 632 kHz** and **halves the node-to-ground fire transient 35 → 17.5 kV** (no node > 21 kV — the open >21 kV split flag resolved); 1C the Cems are resonant **at PRF** (f_res 300 Hz, |Z| 40 Ω torque-carrier) and a **high-Z spectator at f₀** (2.56 MΩ = 8106 × Z₀) → the **Block-D premise is confirmed** and the f₀ reach ring is **not detuned** (frozen resonator_sim holds 14.95 kV, crowbar idle). **Pump→motor power = 4–14 W [IR/EST]** extracted — the Cems are **pump-limited** (their N·I=1650 A-t capacity would need ~290 W; the doubler nets only 6.15 mJ/fire), **replacing the stale ~14 W S5 surplus** with a load-aware range. **PHASE 2 (estimate) → `BALANCE-FAILS`:** the steady drag is **15.6–21.1 W** (windage 0.06–5.6 W over 1–100 Pa, bearing 0.5 W, **core loss 15 W dominant**); the belt covers the rotor, the Cems must cover the **stator drag ≈ 18 W** vs the 4–14 W motor power → **margin −4.3 W**, and the contra-rotation spin-up **does not close** — the motor is **pump-AND-core-loss-limited** (15 W core loss alone exceeds the available power). A modest core-loss cut (15 → ~8 W) + the upper-route 14 W would flip it to `BALANCE-TIGHT`/`CLOSES`. **The electrical operating point is sound (Phase 1); the open question is the iron/mechanical loss budget — lever: cut the Cem core loss (lamination/less steel/lower flux).** Frozen empty-diff asserted; **not merged**.
- **S6 — reluctance regeneration coupling (L(θ) overlay → rotation sense + best regen node) → `COUNTER-ROTATING` + `REGEN-CLOSES-AT-CORE` + `REGEN-TRIVIAL` (branch `s6-regen-coupling` off `main`)** — decides where the S5 resonator surplus taps into the Block-D C-EMs so it adds counter-rotation torque instead of braking; reluctance torque T=½·i²·dL/dθ is polarity-blind, so only timing decides drive vs brake. **Parallel-producer** (like Block D): reads the Block-D C-EM map + the **frozen** `shuttle_event_angles.csv` fire clock + the S5 surplus; never feeds `solveDoubler4`/`shuttle_core`. New **`sim/s6_regen_coupling.py`** (read-only L(θ) profile + fire-clock overlay + node scoring + A0–A4 + §8 checks; **frozen empty-diff asserted** on shuttle_core/reference/index.html/resonator_sim), `sim/s6-regen-coupling-findings.md`, `s6_lqtheta_overlay.png`, `s6_node_tap_scores.csv`. **A0 self-tests PASS** (L(θ) 60°-periodic, max at alignment/min at mid-gap, group-A/B rising windows offset = half pitch — the Block-D line-51 no-dead-spot invariant). **All 6 §8 checks PASS.** **`COUNTER-ROTATING`:** the fire clock fires group A @ SG3b 16.05° and group B @ SG4b 46.05° — **30° apart, matching the 30° group offset**; both strokes sit **mid rising-L** (15° margin to each window edge), single consistent sign → Block D's counter-rotation assertion **holds against the geometry (verified, not asserted)**, with a ±15° as-built datum tolerance. **`REGEN-CLOSES-AT-CORE`:** node scoring (priority phase > isolation > V-match > non-disturbance) picks the **core-direct 9/10 gap that doubles as the governor** (score 7 vs transfer-cap 6, governor-reroute 5) — one element fires on (core > 15 kV) AND (rotor in rising-L), shedding the excess *through* the Cems; regen stations 16.05°/46.05° (the rising-L window centres) returned as the DXF instruction. **But `+ REGEN-TRIVIAL`:** the surplus (14 W ÷ 600 Hz = **23.3 mJ/fire**) is **0.13 %** of the Cem per-stroke copper loss (E_mag = ½·(μ₀·A_gap/l_gap)·(N·I)² = 14.1 J/coil → 17.7 J/stroke at Q≈30) — a negligible trim, not a sustaining regen; the positive-feedback loop has gain ≪ 1 and is bounded by the 15 kV governor threshold (no runaway). **The architecture works (correctly phased, best node found, stable) but the recycle doesn't pay** — the no-consumer machine stays a build-then-hold dissipator; keep the simpler S5 dissipative governor unless the surplus ever becomes material. Provenance flag: the DXF r0_6 has no C-EM/pole layers (stations from Block D §2; as-built pole datum needs the next DXF rev). Frozen empty-diff asserted; **not merged**.
- **S5 — self-consistent operating point + dissipation → `OPERATING-POINT-STABLE` + `DIELECTRIC-Q-FLAG` (branch `s5-operating-point` off `main`)** — retires the last *assumed* drive-side quantity (the absolute island fire voltage) by closing the pump↔tank↔clamp loop self-consistently, then adds the dissipation budget so the operating point is real, not anchored. **Consumer-only:** the pump scale + island ledger from the frozen `shuttle_core` (regression anchor z=1.2033); the tank + two-tier clamp the **unmodified** `sim/resonator_sim.py`; S5 wraps a fixed-point solver around them. New **`sim/s5_operating_point.py`** (A0–A4 + §8 named checks; **frozen empty-diff asserted** on `shuttle_core`/`reference`/`index.html`/`resonator_sim`), `sim/s5-operating-point-findings.md`, `s5_operating_point.csv`, plots (`s5_operating_margin.png`, `s5_dissipation_budget.png`); + a one-line S5 update routed onto the s2recheck-s3 "15.5 kV tight" caveat. **A0 gates PASS** (f₀/Z₀ 635.5 kHz/315 Ω guards 123 µH/960 pF leaks; regression z=1.2033; eta 0.990; frozen clean). **All 7 §8 checks PASS** (incl. energy balance E_inj=lossR+stored+crow+glow rel 2.5e-4, ceiling guard, convergence, margin). **`OPERATING-POINT-STABLE`:** the loop pins V_fire to the **gap** (not the anchored 20 kV) — at the recommended **6.0–6.5 mm** gap V_fire = **18.7–20.3 kV** (< 21 kV C1/C2 ceiling), the governor parks V_tank at 15 kV with the crowbar idle, and the cold single-kick peak gives **+12.2 % / +21.5 % margin** (vs the old 5.5 mm gap's tight +2.8 %) across Q = 320/500/900 — **the S3 "15.5 kV cold is tight" caveat is RESOLVED and PINNED**, η_build = 0.795. **Dissipation budget (the new piece):** governor sink 14.4 W (parked-hold shed), arc 0.05 W, windage/glow ≈ 0 (vacuum), bearing ~O(1 W) [RH]; and a **`DIELECTRIC-Q-FLAG` [IR]** — garolite tanδ≈0.02 → Q_diel≈50 makes the dielectric **96 % of the AC ring loss** (53.6 W of the lumped 55.8 W), which would `DISSIPATION-LIMIT` a *parallel-ring* tank, **but the v0.11 series-DC-hold topology (coil-topology) is robust to it** (the reach is single-kick / Q-**independent**, and the DC hold has no AC dielectric loss) → hold power ≈ **14 W (series-hold)** vs ≈ 70 W (parallel re-ring). **Build dynamics:** M2 single-kick (1 fire → 15 kV, 1.67 ms) cross-checked against the multi-fire reality (~6 fires / 10 ms, the M2-PARTIAL series-DC accumulation from island-charging/series-resonator). Terminal drive-side characterization — no consumer (TMD) → no S6; remaining (TMD-gated) S4 vacuum-gap flashover + thermal anchor on this settled point. Frozen empty-diff asserted; **not merged**.
- **Split L_R + bifilar self-resonant coil study → Part A `SPLIT do-it` (node stress ×0.50, clears C1/C2 overstress) · Part B `ANTINODE-STRESS-DOMINATES` → `SIMPLE-DOWNBACK-PREFERRED` (branch `coil-topology` off `series-resonator` `b62e642`)** — evaluates (A) splitting L_R into two L_R/2 halves at each end of C_R, and (B) the per-hub coil topology the split opens (simple down-and-back vs Tesla-bifilar treated as a **self-resonant helical resonator**). New **`sim/coil_topology.py`** (split + mutual-coupling model + distributed/helical self-resonant treatment + 7 self-tests; geometry from the **DXF r0_6 + freeze-doc §3** — *not* index.html; inherits L_R 79 µH/C_R 789 pF/f₀ 637 kHz, the 36-turn conical coil, the series ~35 kV node-5 transient, and the rev-3 C1/C2 21 kV binding + creepage flag; **0 producer edits**, frozen incl. index.html byte-identical asserted), `coil-topology-findings.md`, `coil_topology.csv`, plots (`coil_transient_split.png`, `coil_standing_wave.png`, `coil_srf_modes.png`). **Ordinary distributed-circuit EE — no DCCREG** (L, M, self-C, SRF, standing-wave profile, helical Q; refs Medhurst, helical-resonator theory, Kuffel/Zaengl). **7 self-tests PASS** (a split M=0→L_R; b 35→17.5 kV node-to-ground; c down-and-back fields-add 300 µH, opposed→15.8 µH non-inductive trap; d self-C bifilar 790 ≫ simple 4.8 pF; e SRF lumped 8.2 MHz vs quarter-wave 6.4 MHz agree; e2 bifilar SRF tuned to f₀; f antinode stress hand-calc). **Part A (clean win, DO IT):** `SPLIT-L` two L_R/2=39.5 µH aiding (k 0.30) → L_total 102.7 µH, f₀ 637→559 kHz (restore via C_R 789→608 pF or size the halves); `TRANSIENT-RELIEF` the ~20 kV L_R swing shares as two ~10 kV drops → node-to-ground **35→17.5 kV (×0.50)**; the asymmetric 35 kV *overstresses* the C1/C2 7 mm-air binding (21 kV) on every fire, and the split brings it to 17.5 kV **below 21 kV** — it fixes a real overstress, and clears a clean/ribbed creepage edge (≥30 kV) → buys margin above the 15 kV op before r0_10 is drafted. **Part B:** `DOWNBACK-L` fields-add 300 µH (opposed = the non-inductive trap, flagged); `SELF-C` simple 4.8 pF (~solenoid) vs Tesla-bifilar 790 pF (×165, tuned to land SRF on f₀); `SELF-RESONANCE` simple SRF **8.2 MHz ≫ f₀ → lumped inductor**, bifilar SRF **tunable to 637 kHz = f₀** (design point), G≈Q≈**408**, coupled even/odd modes **f₊ 559 / f₋ 761 kHz** (symmetric fire selects f₊), Q_sr **408** comparable to lumped ~500 — the self-resonant coil (AC ring in the coil, DC in C_R) is *electrically* viable. **But the decider — `ANTINODE-STRESS`:** the quarter-wave antinode concentrates the resonant voltage onto a few inter-filar gaps at **2.9 kV/mm (split) to 5.8 kV/mm (unsplit)** — at/above the **3 kV/mm air limit** (margin only 1.03× even at the clamped lower bound; G≈408 magnifies any unclamped buildup, and the tighter filar gap needed for the self-C worsens it), manufacturing the **air/surface failure mode rev 3 identified, inside the winding**. **Top-level `ANTINODE-STRESS-DOMINATES` → `SIMPLE-DOWNBACK-PREFERRED`:** do the split; take the simple down-and-back (low self-C, lumped, operate ≪ SRF); the self-resonant bifilar's upside is real but the antinode air/surface stress kills it for this machine. Dispositions reported (`PARASITIC`/`LUMPED-TANK`/`SELF-RESONANT`) for the TMD gate. Frozen modules byte-identical; not merged.
- **Battery energy capacity (rev 3): re-run from DXF + freeze-doc (index.html is STALE) → `BINDING-ELEMENT`=C1/C2 7 mm air/21 kV, `BATTERY-CEILING`=21 kV/174 mJ, `DIELECTRIC-NOT-LIMIT` (garolite 180 kV), creepage FLAGGED (branch `battery-capacity-dxf` off `series-resonator` `b62e642`)** — **source correction:** rev 2 pulled geometry from `index.html` and called it authoritative; that is **wrong — `index.html` is STALE**. Re-derived from the authoritative geometry (the **r0_6 DXF** via ezdxf + the **consolidated freeze-doc `varcap-design-freeze-v0.10.md` §3**), which **reverses rev 2's two stale "corrections"**. **STANDING CORRECTION (all future work): the geometric reference is the DXF + the v0.10 freeze doc; `index.html` must not be used for dimensions (only as a flagged `[STALE]` cross-reference).** Rewrote `sim/battery_capacity.py` (DXF-sourced survey: reads radii + insulation layers via ezdxf, axial gaps from doc §3, cross-checked on r387; **0 producer edits**, frozen incl. index.html byte-identical asserted), `battery-capacity-findings.md`, `battery_capacity.csv`, plots. **rev 2 errors reversed:** C1/C2 is **7.0 mm air → 21 kV** (not the stale 0.5 mm/1.5 kV) and doc §4 states it *caps the island at ~21 kV* (fire window 16.6–21 kV) → the documented system ceiling, back in contention; C_R is **12 mm garolite → 180 kV** (not the stale 10 mm mica/400 kV); and v0.10's C_R is **annular at r387** — rev 2's "central void 20 mm/creepage 30 mm" were stale index.html artifacts. **6 self-tests PASS** (a C1/C2 7 mm=21 kV; b garolite 12 mm=180 kV; c DXF↔doc r387 cross-check; d Cx air+mica air holds 98 %; e DXF carries the insulation layers; f fire gap 5.5 mm=16.5 kV in-window). **Verdicts:** `BINDING-ELEMENT` = **C1/C2 7 mm air, 21 kV** (documented ceiling, doc §4); `BATTERY-CEILING` = **21 kV / 174 mJ**, operating 15 kV/88.8 mJ → **1.40× V, 1.96× E margin** (matches the doc's comfortable window); `DIELECTRIC-NOT-LIMIT` — garolite bulk 180 kV ≫ 21 kV (**8.6×**), robust to the source error (held for stale mica 400 kV, holds for real garolite 180 kV). **⚠ FLAG (load-bearing, to TMD):** the **C_R edge creepage is undimensioned** in the r0_6 *radial* template — a bare-edge estimate (≈12 mm septum) gives 12–30 kV, at/below the 15 kV operating point, so a validated design must have radial overhang/ribs the radial DXF doesn't show; it is the binding unknown, *excluded* from the ceiling (rather than letting a guess override the documented 21 kV) pending the not-yet-drafted **r0_10 DXF**. **Provenance flags:** the brief's "DXF v0.11" is **absent** (repo has r0_6 + v0.10 doc; doc §8 cites the missing r0_10); the r0_6 DXF is a 2-D radial template (radii only — R387 confirmed; axial gaps from the doc). **RAISE-LEVER:** widen C1/C2 air (+3 kV/mm), C_R creepage ribs/overhang (resolve r0_10 first), guard-ring the plate edges — not the garolite. Frozen modules byte-identical; not merged. *(Supersedes the rev-2 `battery-capacity` branch, which used stale index.html dimensions.)*
- **Series-resonator output stage (L_R in series with C_R, 5–6) → `SERIES-HOLDS-DC` · `REACH-DC-15kV` in 6 fires · `OVERSHOOT-SELF-LIMITS` · `QUENCH-SERIES-CLEAN` · `DC-AC-SPLIT={15kV, 20kV}` · η_machine 0.445 (branch `series-resonator` off `island-charging` `d0ef6f6`)** — re-sims only the post-fire output stage with L_R *in series* with C_R (5 — L_R — junction — C_R — 6) so **C_R blocks DC and becomes the DC battery**, dissolving the multi-fire accumulation problem the parallel tank (L_R ∥ C_R, shorts DC, rings down) could never hold. New **`sim/series_resonator_output.py`** (series fire ODE + accumulation loop, own RK4 integrator; consumes the inherited island source Q_isl 1.395 µC / E_fire ~14 mJ / W_coll 12.45 mJ @ `d0ef6f6`, W_mech,stator 15.94 mJ @ `84fcaaa`, fire-ODE form @ `05ccf60`; **0 producer edits**, `shuttle_core`/`reference`/`index.html` byte-identical asserted), `series-resonator-findings.md`, `series_resonator.csv`, plots (`series_vcr_accumulation.png`, `series_5_6_waveform.png`, `series_dc_ac_split.png`). **Key coupling:** C_R holds a standing bias, so the gap strikes at V_island−V_CR=V_breakdown (~20 kV) — the island collapses *further* (C_fire 70→42 pF) as V_CR climbs 0→15 kV; the island can over-reach (175 kV ceiling) so the **15 kV clamp, not the island, caps V_CR**. **6 self-tests PASS** (a series half-period quench 0.225 µs; b C_R holds DC & accumulates; c converges to steady 15 kV; d clamp self-limit, island over-reaches to 15.1 kV; e per-fire energy closure rel 6e-8; f inverse experiment — force-drain → no accumulation, recovering the parallel-tank ring-down). **Result:** C_R accumulates to **15 kV DC in 6 fires** (~14 mJ/fire) — the inverse of the parallel-tank ring-down. Despite a mismatched mid-collapse swap (island fires at ~70 pF into 789 pF → only ~30 % energy transfer per fire), the small high-V island **charge-reverses** through L_R, dumping a large ΔQ ≈ 2.56 µC/fire, so the 20 kV breakdown differential re-established each fire pumps C_R to the clamp in 6 kicks. The gap quenches at the series current-zero (~0.17–0.23 µs), C_R left charged. The steady 5–6 waveform decomposes into a **flat 15 kV DC bias on C_R + a brief 20 kV AC transient across L_R** per fire. **η_machine = 0.445** (corner-independent; arc 20/35/50 V identical — the swap is breakdown-differential-driven, not arc-limited): the C-C taxes are unchanged from the island-charging block (~0.48), but the energy now **stays** on C_R instead of ringing away, so the multi-fire reach **succeeds and holds**. The earlier escalation (reach is multi-fire, not single-kick) stands, but the series topology makes that multi-fire reach achievable — C_R is the DC battery, no separate hold cap, L_R doing double duty (resonant charge + current-zero quench). Frozen modules byte-identical; not merged.
- **Island-charging steady-state co-sim → resolves M1 vs M2 → `M2-PARTIAL`, `ISLAND-FIRE-ENERGY = 14.0 mJ`, kick-count 6.5, η_machine 0.484 (physical) (branch `island-charging` off `machine-energy-balance` `05ccf60`)** — sources the island fire self-consistently, replacing the prior block's unsourced 130 mJ assumption (which gave the impossible η_machine = 7.3 > 1) and resolving the M1-vs-M2 coupling choice deferred since project start (`s2_coupling.py:14` was BLOCKED on it; `run_X1` anchored the island at 20 kV *by assumption*). New **`sim/island_charging_cosim.py`** (steady-state iteration + charge/energy ledger are new; consumes the frozen cap topology Cx 8↔648 pF + 8 pF boss, Ca/Cb 309 pF, z=1.307, and inherited anchors η_fire 0.985 / W_mech,stator 15.94 mJ / useful_per_fire 6.15 mJ; **0 producer edits**, `shuttle_core`/`reference`/`index.html` byte-identical asserted), `island-charging-findings.md`, `island_charging.csv`, plots (`island_energy_ledger.png`, `island_kickcount.png`, `island_rail_sensitivity.png`). **Decisive physics:** E_fire = ½·Q·V_strike is set by the charge the rail sources, bounded by two independent per-cycle ceilings — the **charge/dilution** ceiling (309 pF rail diluted by the 648 pF island to 6.46 kV on first pickup; the pickup is a C-C equalization, the same two-cap tax as the stator core, keeping only **24 %** of drawn energy) and the **energy/budget** ceiling (doubler nets only **6.15 mJ/cycle**). **5 self-tests PASS** (a M1 literal limit = 1.58 mJ continuity; b steady-state convergence rel-spread 2e-16; c ledger closure rail-draw+collapse=E_fire+pickup-loss rel 8e-16; d M2 ceiling 12.96 µC/129.6 mJ; e rail-dilution 6.46 kV < 20 kV). **Verdict `M2-PARTIAL`:** the physical spark gap fires **mid-collapse** at ~70 pF every cycle, delivering **E_fire ≈ 14.0 mJ** (robust 14–17 mJ over the rail sweep) — an order below the 130 mJ M2 reservoir but well above the 1.6 mJ M1 bucket. So the 89 mJ tank takes **~6–7 fires**: the **single-kick reach is WRONG (multi-fire) — escalate**; the "isolated knock" must be reframed as a pumped swing of ~6–7 × 14 mJ. **η_machine = 0.484 is now physical (<1), resolving the prior >1 paradox:** the literal-1.6 mJ block charged W_mech,island with the wrong (8 pF bucket) charge; at the sourced charge (1.40 µC) the **rotor's collapse mech work ½Q²Δ(1/C) = 12.4 mJ dominates E_fire** (the rail only seeds 1.5 mJ after the 4.7 mJ pickup tax), and once counted on both ledger sides η_machine = **0.48–0.55** (not the optimistic 0.88). M2 fails two ways: the gap fires mid-collapse before 648 pF is reached, and *forcing* M2 needs **37 accumulation cycles/fire** (η_machine 0.22). The reach floor is still clearable in energy but not in one kick; the margin must be re-derived in the multi-fire regime. Frozen modules byte-identical; not merged — re-opens the reach for TMD review.
- **Island→tank fire-path energy balance + whole-machine efficiency → `FIRE-PATH-RECOVERS` · `S2-ETA-CONFIRMED` · `QUENCH-AT-ZERO-CLEAN` · `ENERGY-BALANCE-GAP` (η_machine>1, escalate) (branch `machine-energy-balance` off `energy-balance` `84fcaaa`)** — the machine-level answer to "mechanical work in vs tank energy out". The stator block found the 4-node core only 38.6 % efficient (61 % C-C tax) but flagged the ~89 mJ kick is the **island Cx→tank C_R** fire, an inductive **C-L-C** swap that should bypass that tax. New **`sim/fire_tank_transfer.py`** (a **new time-domain RK4 ODE** — NOT consumer-only; the frozen quasi-static solver shorts the 5–6 tank and cannot do the L-coupled dynamics — but all *state* is consumed from the frozen `shuttle_core` trace + Block R; **0 producer edits**, `shuttle_core`/`reference`/`index.html` byte-identical asserted), `machine-energy-balance-findings.md`, `machine_energy_balance.csv`, plots (`fire_transfer_trace.png`, `fire_loss_ledger.png`, `machine_eta_vs_corner.png`). The loop ODE `L_eff·dI/dt = V_island−V_tank−V_arc·sgn(I)−I·R_loop` (+ dV_isl/dt=−I/Cx, dV_tank/dt=+I/C_R) integrated from the pre-fire island (Cx 648 pF @ 20 kV → 130 mJ) to the **first natural current-zero** (no cutoff). Params cited (C_R 789 pF, L_R 79 µH, V_arc 20/35/50 V + τ_rec 10µs/100µs/1ms from `shuttle_core.py:685-687`); **L_loop≈1 µH / R_loop≈0.5 Ω flagged `[IR]` undocumented**, swept, both sub-dominant (L_eff≈L_R; loss arc-dominated). **5 self-tests PASS** (a lossless matched swap η→1; b arc-dominated η collapses 0.98→0.36, localizer attributes to arc; c energy closure delivered+arc+loop+residual=E_pre to 6.9e-8; d 88.8 mJ tank scale; e τ_quench=0.530 µs=π√(L_eff·C_eff)). **The fire path RECOVERS:** η_fire = **0.985** (opt/mid/pess 0.9868/0.9853/0.9838), reproducing S2's matched-cap **0.9904** within ~0.5 % (arc drop + ~1 % first-zero residual on the mismatched 648/789 island) → **`S2-ETA-CONFIRMED`** + **`FIRE-PATH-RECOVERS`** (98.5 % vs the stator's 38.6 % — the inductive swap bypasses the C-C tax). **`QUENCH-AT-ZERO-CLEAN`:** extinguishes at the first current-zero (0.530 µs); arc τ_rec (10µs–1ms) ≫ ring-back (2·τ_quench = 1.06 µs) → no re-conduction before the tank rings back, at every corner (the S3-deferred local-loop question, answered). **But `ENERGY-BALANCE-GAP` (escalate):** per the user's **literal-trace** decision, `W_mech,island` is the flying-bucket ½Q²Δ(1/C) from the frozen trace = **1.58 mJ** (the collapsed 8 pF bucket holds only 1.6 mJ at 20 kV), so `η_machine = E_tank,delivered/(W_mech,stator 15.94 + W_mech,island 1.58) = 127.7/17.5 = ` **7.3 > 1 — UNPHYSICAL.** The efficient fire delivers ~128 mJ from a 648 pF/130 mJ island, but the **literal flying-bucket shuttle trace performs only 17.5 mJ of mechanical work per fire** → the **M2 island-dump (the 130 mJ reservoir the S2/S3 89 mJ single-kick reach relies on) is not energetically sourced by the M1 flying-bucket trace** the rest of the campaign runs on. The gap names the unaccounted ~130 mJ island-charging work: either it is a real (unmodelled) mechanical input (M2 real → η_machine≈0.88) or the literal machine delivers ~1.6 mJ/fire and the tank needs ~80 fires (not single-kick). **The reach margin rests on an island-charging energy the shuttle trace does not contain** — re-examine via the deferred self-consistent S5 co-sim. The fire *path* is not the problem (it is efficient); the *sourcing* of the M2 island is. `MACHINE-ETA` is a flag, not a number. Frozen modules byte-identical; not merged — left for TMD review.
- **Electromechanical energy balance (mechanical shaft work in vs tank energy) → `ENERGY-BALANCE-CLOSES` · `EQUALIZATION-TAX-PRESENT` (branch `energy-balance` off `s2recheck-s3-spark`, the 789 pF head)** — a **second conservation law** (energy) laid over the charge-law z campaign; de Queiroz's z explicitly excludes electromechanical forces, so this fills that gap and cross-checks the pump from the energy side. New **consumer-only** `energy_balance_from_solver.py` (+ 5 self-tests), `energy-balance-findings.md`, `energy_balance.csv`, `energy_balance_flow.png` (W_mech → ΔE_stored + E_tax bar), `energy_balance_tau.png` (τ profile). Reads the FROZEN `solve_doubler4(trace=True)` ("traceDoubler4") + reuses `charges_from_voltages`; recomputes **no** electrical solve — the only linalg is the *constant-charge* cap-change step (pure mechanics, no diodes) + energy bookkeeping. **0 producer edits** (`shuttle_core`/`reference/doubler_core.py`/`index.html` byte-identical to base, asserted). **Base flagged:** the 789 pF *design* is on `freeze-v0.10` (varcap doc) but the runnable *operating-point preset* `G3-geometry-v010.json` (cR 789) + tank infra are on `s2recheck-s3-spark` → built there. **Method:** inject the G3 caps into the 4-node galvanic core (pumps z=**1.334** = the known ceiling, cross-check); per phase transition split ΔE_stored into the **mechanical stroke** `W_mech = U(Q,C_new)−U(Q,C_old)` (constant-Q, diodes off) and the **diode equalization** `E_tax = U(pre-diode)−U(post-diode)≥0`; the pre-diode endpoint is the constant-Q solve `M(C_new)·V_int=Q` (cap matrix = ∂Q/∂V of the frozen charges fn). **Self-tests PASS** (a single-cap ½Q²Δ(1/C); b constant-Q round-trip 1e-13; c a deliberate mismatched merge recovers a *known* ½(C₁C₂/(C₁+C₂))ΔV² tax — positive control for the localizer; d τ-mean=W/Δθ; e ½C_R·V²=88.8 mJ ≈ S3 floor). **`ENERGY-BALANCE-CLOSES`:** the per-cycle identity `W_mech = ΔE_stored + E_tax` holds to **1.4×10⁻¹⁶** (machine precision), and the **eigen-growth cross-check** `ΔE_stored/U_start = 0.7796 = z²−1` to 2×10⁻¹⁶ — the energy bookkeeping reproduces the charge-law pump growth exactly ⇒ the z campaign is **energetically self-consistent** (independent, second-law confirmation). **`EQUALIZATION-TAX-PRESENT` (the named sub-outcome):** the ideal charge-conservation transfer carries a real, quantified capacitive-equalization loss — **61.4 % of W_mech** at the G3 swing (the two-capacitor paradox at every diode merge, ½CΔV² even with ideal diodes) ⇒ stator-core conversion efficiency **η_conv = 38.6 %** — a real efficiency tax the charge-only analysis could not see. **`ENERGY-BALANCE-GAP` NOT triggered** (no residual beyond the quantified tax). **Honest scope `[IR]`:** absolute per-fire W_mech (15.9 mJ at the 15 kV rail anchor) is ≪ the 89 mJ tank kick because the kick is **island Cx-boost dominated** (not in this stator core); so η is the core conversion `ΔE_stored/W_mech`, **not** the invalid cross-layer `E_tank/W_mech` (>1 — surfaced as a deliberate tell, not smoothed). **η and τ are reported** (η_conv 0.386; τ-ripple ≈7.8, the Block-D motor load) — and **separable** (energy uses only endpoints → robust to C(θ) shape; only τ uses dC/dθ). Frozen modules byte-identical; not merged.
- **S2 reach re-confirm @789 pF (B1) + S3 spark tier (B2–B4) → `REACH-CONFIRMED-789` · `STRIKE-CONFIRMED` · `QUENCH-OK` · `BACKSTOP-CLEAN` · integrated reach clears 15 kV (branch `s2recheck-s3-spark` off `freeze-v0.10`)** — the one combined pass validating the v0.10 freeze (C_R 960→789 pF). New `presets/G3-geometry-v010.json` (G2 clone, `cR` 960→789, +12 mm-disc provenance; G1/G2 not mutated), `sim/s2recheck_s3_spark.py` (**consumer-only**, regression-gated; reuses frozen `shuttle_core` spark machinery + drives the standalone `resonator_sim` tank at 789 pF), `sim/s2recheck-s3-findings.md`, `sim/s3_spark_traces.png`, `sim/s3_spark.csv`. **Gates PASS:** ring f₀/Z₀ **637.5 kHz / 316 Ω** (guards a stale 123 µH/960 pF leak); G3 loaded==expect; **C0 regression** (`assert_ideal_identity` + T0a/T0b/T0c → anchor 1.2033, ideal 1.1894, ledger drift 4.6e-14); frozen empty-diff (checked twice). **B1 entry gate `REACH-CONFIRMED-789`:** smaller C_R is favourable — η 0.962→**0.990**, floor 108→**89 mJ**; island@20 kV → E_M2 **128 mJ** → cold-tank 18 kV → holds 15 kV (easier than the 960 pF run). **B2 `STRIKE-CONFIRMED`:** the drafted 5.5 mm SG3b/SG4b gap (12 mm spheres, 3 kV/mm) strikes the island at **17.2 kV**, inside the 16.6–21 kV window (near the low edge; `paschen_strike`'s 0.5 mm regime deliberately not used). **B3 `QUENCH-OK` + `BACKSTOP-CLEAN`:** arc τ_rec (10 µs–1 ms) ≪ the 1.67 ms favourable half at all corners; frozen `C2_backstop` BACKSTOP-CLEAN (island 0.71× single-bucket ≤ 1.05, a **scale-free** ratio → holds at the v0.10 strike); **BS3/BS4 DXF markers still TODO** (sim runs parametrically on the freeze §5 spec). **B4 integrated reach:** at the **real** fire-gap strike (island 17.2 kV, not the 20 kV anchor) → **94 mJ > 89 mJ floor** → cold-tank 15.5 kV → two-tier clamp holds 15 kV, crowbar idle, sink 3.6 W, conservation +0.03 %. **Honest caveat:** 15.5 kV cold is tight → recommend opening the gap to ~6.0–6.5 mm (island 18–20 kV) for margin, below the 21 kV C1/C2 flashover. **Closes the S2 fire-gap conditionality at 789 pF.** `shuttle_core`/`reference`/`index.html` byte-identical; not merged.
- **S2 pump↔tank coupling (does the real pump deliver the assumed kick?) → `PUMP-DELIVERS-EASED-ONLY` (M2) / `PUMP-UNDERDELIVERS` (M1) — map-dependent (branch `s2-pump-tank-coupling` off `resonator-sim-r2`)** — replaces the parameterised `E_kick` in `resonator_sim` with the **real per-cycle energy the frozen pump delivers** at the grown (r2) geometry, and asks whether it clears the 108 mJ reach floor. New `presets/G2-geometry-r2.json` (G1 clone with island Cx 4/88→**8/648 pF**, C_R 1477→**960 pF** record-only, L_R 79 µH provenance; C1/C2 + Ca/Cb unchanged; G1 not mutated), `sim/s2_coupling.py` (**read-only consumer** of the frozen pump driving the **unmodified** `sim/resonator_sim.py` tank), `sim/s2-coupling-findings.md`, `sim/s2_coupled_traces.png`, `sim/s2_E_deliver.csv`; brief saved to `docs/briefs/`. **All §8 checks PASS:** ring f₀/Z₀ 577.9 kHz/287 Ω (guards a stale 123/169 µH leak), G2 loaded==expect, G0 anchor (inj 1.20327), ledger drift 1.2e-13, frozen empty-diff, coupled-chain energy conservation < 0.05 %. **G0** injection VERIFIED; G2 galvanic ceiling 1.334 = G1 (`galvanic_z` independent of Cx/C_R). **P1 — grown bucket pumps HARDER:** z_shuttle **1.2077 (88 pF) → 1.3072 (648 pF)** (+48 % above unity, below the 1.334 ceiling), ledger clean (1.2e-13, no `LEDGER-BREAK` — the 648 pF island is a clean shuttle), boost_ratio 40.5. **TMD chose to run BOTH coupling maps (brief §4).** **X1 scale-fix:** the ideal pump is **scale-invariant** (eigenvector grows by z, no absolute volts), so the absolute delivery is set by the operating-point anchor (island fire = design HV 20 kV, `[IR]`), not the pump. **The two maps BRACKET the 108 mJ floor:** **M2 island-dump** (η = 96 % LC transfer of the 648/960 pair) → **124.7 mJ → `PUMP-DELIVERS-EASED-ONLY`** (cold-tank 16.1 kV); **M1 rail-increment** ((1−1/z)·C_R·V² = 90.2 mJ) → **`PUMP-UNDERDELIVERS`** (13.7 kV). **C1:** driving the unmodified tank, M2 delivery **HOLDS 15 kV** (governor sheds 10.5 W, crowbar idle, all Q); M1 under-reaches 13.7 kV. **Working verdict `PUMP-DELIVERS-EASED-ONLY`** (M2, the migration-doc island-dump): eased reach is real, the ~6 % margin is the true ceiling, full-drive +25 % headroom was **paper**; M1 is the conservative bound. Result is **map- and scale-sensitive** — the absolute island fire voltage (anchored 20 kV; 18/20/23 kV → 101/125/165 mJ) is the swing variable, to be pinned by the self-consistent S5 co-sim. **Resolves r2 conditionality:** `TANK-HOLDS-15kV` stands under M2/eased, conditional-unmet under M1. `shuttle_core`/`reference`/`index.html` byte-identical (asserted); not merged.
- **resonator-sim r0.2 (revised geometry; confirm 15 kV + clamp hold) → `TANK-HOLDS-15kV` (branch `resonator-sim-r2` off `resonator-sim`)** — re-run of the standalone tank+clamp model at the **revised geometry** that closes the r0.1 17× reach gap. The three coordinated changes (brief §2–3): island **Cx 88→648 pF** (now ≈ tank C_R → efficient charge-sharing), **C_R 1477→960 pF** (8 mm garolite), and the **conical-hub L correction 169→79 µH** (the cylindrical 169 µH was a mis-model; f₀ 318→**579 kHz**), with the target softened **20→15 kV**. Code moved to `sim/resonator_sim.py` (re-parameterised; new `sim/resonator-r2-findings.md`, `sim/resonator_r2_traces.png`, `sim/resonator_r2_sink.csv`; brief + hydraulic-philosophy doc saved under `docs/briefs/`). Still **standalone** (imports none of `shuttle_core`/`reference/doubler_core.py`/`index.html`); numpy+matplotlib hand-rolled RK4. **R0 PASSES** (f₀ 577.9 kHz vs analytic 0.00 %, τ 0.01 %) — **re-validates the corrected conical 79 µH** (the 169 µH cylindrical model would give 318 kHz, falsified); energy-conservation gate < 0.03 % across all stages. **R1 reach CONFIRMED:** full drive (171 mJ) → **18.8 kV**, eased (115 mJ) → **15.4 kV**, both ≥ 15 kV at all Q; **single-kick** (accumulation ×0.99 — still kick-and-decay at 600 Hz) so reach is **Q-independent**; **+25 % headroom**, and the full drive can fall 37 % (171→108 mJ) and still hit 15 kV. **R2:** confirms the r0.1 placement finding — a **void** shunt bleeds but the impulsive kick spikes the peak past V_glow (peak ~18 kV); the **upstream/island** governor caps the peak **exactly at V_glow** (15 kV). **R3:** crowbar **idle** under eased nominal drive at ≥ 16 kV setpoint; catches only the full-drive runaway, dumping ~168 mJ/event (~17 MW/10 ns). **R4 the headline:** the two-tier upstream governor + crowbar **HOLDS the tank ≤ 15 kV with the crowbar idle at all Q, both drive modes**; governor **sink load ~39 W (full) / ~4.4 W (eased)** — matching the brief's ~38 W / few-W prediction. **Verdict `TANK-HOLDS-15kV`**: the revised resonator + clamp is validated; recommend **eased drive** (~4 W sink) over full (~39 W) unless the void/structure can carry 39 W (a deferred structural-sizing call, not auto-`SINK-OVERSIZED`). The closed gap is the geometry — matching the island vessel to the tank (hydraulic equal-vessel transfer). Next: **S2** pump↔tank coupling (extract real per-cycle 5–6 charge from `shuttle_core`; drive parameterised here). Frozen solvers + `index.html` untouched; not merged.
- **resonator-sim r0.1 (first live 5–6 tank + clamp architecture) → `TANK-UNDERDRIVEN` (branch `resonator-sim` off `geom-shuttle-gate`)** — the **first** time-domain model of the live resonator tank and the full clamp tiers (design-intent-lock §4–7); every prior run **shorted** the 5–6 tank, so the frozen quasi-static `shuttle_core` cannot simulate it. New **standalone** `resonator_sim.py` (driven parallel-RLC + nonlinear clamp shunts; hand-rolled numpy RK4, scipy-free, crowbar as a discrete event-dump; imports **none** of `shuttle_core`/`reference/doubler_core.py`/`index.html`), `resonator-findings.md`, `resonator_traces.png`, `resonator_sink_energy.csv`. Tank from the brief's geometry+materials (L=169 µH, C=1477 pF, **f₀=318.6 kHz**, Q swept 320/500/900), superseding the code's L_RES=123 µH. Drive is the **open lever**: `shuttle_core` exposes no tank-side delivery, so per-kick energy E_kick is **swept** {5,20,50,100,300} mJ, anchored by the 88 pF island estimate ½·Cx·(20 kV)² ≈ **17.6 mJ**. **R0 authoriser PASSES** (free-ringdown f₀ error 0.00 %, τ error 0.01 % vs analytic; energy-conservation gate < 0.1 % across all stages). **R1 headline:** at the physical ~18 mJ/kick the tank reaches only **~5 kV**; 20 kV on the 1477 pF tank needs **~295 mJ (~17×)**, i.e. the 88 pF island at **~82 kV** — implausible. With τ≈0.5 ms vs 1.67 ms kick-spacing (600 Hz, both branches) the tank **decays between kicks** (accumulation ×1.00–1.01) — **kick-and-decay, not resonant**; Q-sweep confirms (spacing/τ = 5.2/3.3/1.9, never < 1, so higher Q cannot close the gap). **R2:** the soft glow governor's **placement is decisive** — a **void** shunt bleeds energy (Q-spoil up to 2.2) but the impulsive ~10 ns spark spikes the peak past V_glow before a µs-scale shunt responds; the **island/upstream** placement caps the peak exactly at V_glow (favours upstream, lock §6.3). **R3:** crowbar **idle** under nominal drive (0 fires); under over-drive it dumps **~491 mJ/event (~49 MW/10 ns)**, threshold-independent (impulse overshoots every setpoint) — the MW-class full-tank dump the lock §6.2 anticipates, sizing the deferred sink. **R4:** the two-tier clamp **HOLDS ≤ 20 kV with the crowbar idle at all Q** at an adequate design drive — so the **clamp architecture is validated**; the open problem is the *drive*, not the clamp. Levers named (grow Cx→C_R, raise PRF so spacing<τ, resonant-sync). Negative headline is the deliverable; nothing retuned. Frozen solvers + `index.html` untouched; not merged.
- **geom-shuttle Phase-7 (first geometry-fed pump) → `GEOM-PUMP-CONFIRMED` (branch `geom-shuttle-gate` off `main`'s canonical solver line `effcee1`)** — the first run of the **real buildable geometry** (DXF r0.6, Z-stack true-scale caps) through the canonical `shuttle_core`, replacing the campaign's placeholder caps. New `presets/G1-geometry-r06.json` (raw geometry caps C1/C2 16/280, Cx 4/88, Ca/Cb 309, C_R 1477 record-only, Cpar 20; `expect` self-test block), `geom_shuttle_run.py` (pure consumer: G0→G3), `geom-shuttle-findings.md`, `geom_caps_vs_placeholder.csv`. **`shuttle_core.py` carries ONE additive, TMD-authorised change** — a default-preserving cap-injection hook `set_device_caps()`/`reset_device_caps()` + `device_caps_selftest()` (+40 lines, 0 deletions; the documented device-point scalars are the injection point, only `Cx` was a `Params` knob). Rev-0.3 path **byte-identical** (hook inert by default): `--rev03` anchor 1.2033, spark C0 `T0a 1.2033 · T0b 1.1894 · drift 4.6e-14` all green; `reference/doubler_core.py` + `index.html` untouched. **G0 INJECTION-VERIFIED, anchor reinterpreted:** placeholder resets to z=1.20327 exactly (injection proven); the **geometry caps' own galvanic ceiling is 1.334** — which **independently reproduces the chat-side port's z≈1.335** (the brief said that number "failed"; the canonical solver confirms it). `Z_BASELINE=1.2033` is the *placeholder* device point's ceiling, not a cap-invariant; the brief-literal "Ca/Cb→large→1.2033" does NOT hold (Ca/Cb≫C1 shorts the pump ⇒ z→1.000), reported as a finding. **G1 the headline:** ideal-tier `z_geom=1.20766 > 1` and **above** the placeholder `z=1.18938` (+9.7% rel.) — the buildable geometry **pumps, harder than the placeholder**, because Ca/Cb=309 pF now exceed the swinging C1max=280 (placeholder reservoir 100 was tiny vs 1000 swing); z_geom sits below its own 1.334 ceiling (consistent). **G2 fires with headroom:** effective boost ratio drops 17.65×→7.33× (fixed boss/gap strays 8 pF dominate cx_min=4), but the scale-free fire margin (island overvoltage / source rail) is **1.16 vs placeholder 0.15** — the larger Ca/Cb load the island higher, so it fires *more* comfortably; the ~14× smaller per-fire charge (Cx 88 vs 1200) is throughput (z>1 survives it), not a fire blocker → **no GEOM-FIRE-MARGINAL** (absolute-strike confirmation deferred to the spark tier once gap electrodes are placed, §7). **G3 firing order HOLDS:** SG1/SG2-lead SG3/SG4-lag at the as-drawn 30°/no-offset (the brief flagged this as "expected to possibly fail"; it does not — no island timing offset required); gap stations (SG1 0.05 … SG4b 0.7675 sector) output as the placement target for the next DXF. Caps consumed from the preset, not hard-coded; consumer re-implements no solver internals. Not merged.
- **xsim Phase-6 rev 0.5 (V0 hardening + X2/X3 + dt-sweep) → `V0-SECONDARY-OPEN` · `X2-B XSIM-MATCH` (3 corners) · `X3-B STRUCTURE-CONFIRMED` · `T3 DT-PLATEAU` (branch `claude/feasibility-approval-planning-5gkcam`)** — extended the (B) analytic eigen-witness to the arc and bootstrap tiers + added a ngspice timestep diagnostic. `xsim_queiroz_matrix.py` gains `_newton_zab` (Newton engine, unit-checked on √2), `queiroz_fig1_newton` (T1), `arc_limit_cycle`/`_arc_phase` (X2), `bootstrap_structure`/`boot_classify` (X3); `xsim_from_solver.py` gains the X2/X3 table rows + `dt_sweep` (T3) + plots (`xsim_x2_arc_corners.png`, `xsim_x3_bootstrap_structure.png`, `xsim_dt_sweep.png`). **T1 V0-SECONDARY-OPEN:** the Newton engine works, but Queiroz's Fig-1 z=1.1538 is NOT reproduced — his segment *restrictions* are given but not his Fig-1 cap/diode **topology**, and the paper is unfetchable in-environment (arxiv/IEEE/coe.ufrj.br all 403); reconstruction attempts give pumping doublers at z∈{1.0,~2.08} not 1.1538, reported as an honest residual (not a 'topology' hand-wave). X1-B authorisation therefore stands on the in-repo galvanic anchor (eigen z=1.2033, Δ=−4e-16, exact). **X2-B XSIM-MATCH (all 3 corners):** the absolute-volt Paschen strike breaks scale-invariance ⇒ z is a limit-cycle property (the genuine §3.1 case); the fire opens at the **absolute strike crossing** (emergent, read not clocked) with partial transfer φ=1−pVarc/ov, and z_arc (geometric-mean growth-window gain of the **independent** solver) reproduces native **opt 1.18877 / mid 1.18440 / pess 1.16666 to MACHINE PRECISION** (Δ≤6e-6), with the island-overvoltage **clamp≈1.01–1.04× strike** (native ~1.04). Strike (650/333/150 V) and pVarc (20/35/50 V) **consumed**, not tuned. **X3-B STRUCTURE-CONFIRMED:** with V_FLOOR=327 (rail no-fire floor) + tau_storage leakage consumed, trajectory classification (no-fire/fire-and-decay/growth) backs out **V_floor < V_sustain**, **V_sustain RISES as rpm falls** (mid 160→230→520 @3000/1519/769), and **pess non-self-sustain ≤3000 rpm** — all reproduced (the structural test, brief §4); magnitudes softer than native (V_floor 120 vs 187, V_sustain 160 vs 437 — the low-V retention model sustains more easily), reported honestly (≤15% magnitude band not met; ordering/direction is the load-bearing test). **T3 DT-PLATEAU:** sweeping the X1-A max-timestep 30× (Δt=T/{400..12000}) leaves z at ~1.05 (1.0544→1.0592, Δz=+0.005), NOT trending toward native 1.18938 ⇒ the X1-A under-pump is **STRUCTURAL** (zero-time cluster re-solve vs finite-rate integrator), not numerical — the §3a mechanism-(1) attribution is now EVIDENCED. **Three independent constructions agree on X1 (native forward · B eigen) and X2 z_arc (native spark · B eigen) to machine precision.** Combined: X1 PASS on B · X2 PASS on B (3 corners) · X3 structure on B; A's divergence is the named, T3-confirmed continuous-time artifact. Independence preserved (grep-gate: 0 native-solver calls). Native modules untouched (mirror FAITHFUL, C0 green); not merged.
- **xsim Phase-6 rev 0.4 (dual witness) → `X1-B XSIM-MATCH` (analytic eigen-witness) · `X1-A XSIM-DIVERGENT` (ngspice) · `X1 PASS on B` (branch `claude/feasibility-approval-planning-5gkcam`)** — added a **second, analytic witness** (B) per the rev 0.4 addendum: `xsim_queiroz_matrix.py`, a **segment-matrix / eigenvalue** solver in the spirit of de Queiroz (*Analysis of Electronic Electrostatic Generators*, IEEE 2018) — z is the **dominant eigenvalue of the per-cycle charge-transfer map** (cycle segmented by conduction state; each segment a nodal charge-conservation relation; composed into one map; eigenvector = steady voltage ratios), with the emergent fire as the collapse sub-step where the boosted island crosses threshold. **Independence verified (addendum §3.3):** B implements its **own** cluster solver and does **not** import `shuttle_core.transition`/`_galv_phase` (grep: 0 calls; consumes only device-point constants + firing **order** + `shuttle_run` as the comparison target) — `shuttle_core` marches **forward in θ** and reads z as the iterated asymptotic ratio, whereas B **never time-steps**, composing segment matrices and extracting z as an **eigenvalue** (genuinely different construction). **V0 authorisation:** the eigen-method recovers the **galvanic anchor z = 1.2033** (Δ=−4e-16, paper-independent, the (B) analog of X0); Queiroz's Fig-1 example (60/360, Ca=Cb=330, paper z≈1.1538) gives 1.326 — does **not** reproduce his number because his exact topology differs from our 4-node galvanic doubler and is **un-fetchable** in-environment (arxiv/IEEE/his site all 403); reported honestly, authorisation rests on the galvanic anchor. **X1-B `XSIM-MATCH-B`:** eigen z = **1.18938** (Δ=−5e-14 vs native) and emergent δ = **0.2175** (Δ=0) — to **machine precision**; δ is genuinely emergent (sweeping the threshold moves it 0.2175→0.36 while **z stays invariant at 1.18938**, reproducing the native pVbkFire behaviour exactly). **Three-way z:** `shuttle_core` (forward) 1.18938 · (B) eigen 1.18938 · (A) ngspice 1.05444 — two independent constructions agree on z **and** δ to machine precision. **The rev-0.3 ngspice (A) is demoted to tertiary** (`xsim_from_solver.py` now runs A, drives B, prints the dual-witness §5 table + three-way line + V0 plot `xsim_queiroz_V0.png`): A still **`XSIM-DIVERGENT-A`** (z=1.0544, δ=0.1917), now **conclusively localised as a continuous-time SPICE artifact** since B matches native — *not* a circuit defect, exactly the addendum's prediction. **Combined X1: PASS on B (primary).** X2/X3 now **admitted** (X1-B passes) but deferred (the eigen arc/bootstrap extension = the genuine Newton/absolute-volt case) — marked BLOCKED-pending, not claimed. Native modules untouched (mirror FAITHFUL, shuttle C0 green); not merged.
- **xsim Phase-6 rev 0.3 (Queiroz unblock) → `X0-RECOVERED` · `X1-UNBLOCKED & PUMPING` · `FIRE-EMERGENT` · `XSIM-DIVERGENT on z` (branch `claude/feasibility-approval-planning-5gkcam`)** — adopted the **De Queiroz source-imposed charge-transfer** method (addendum rev 0.3) to clear the rev-0.1 X1 blocker, **without touching** `shuttle_core.py`/`reference/doubler_core.py`/`index.html`. `xsim_netgen.py` gains `netlist_x1_shuttle` (+ `_island`/`_cx_wave` helpers); `xsim_from_solver.py` gains the X1′ run, the fire-angle readout, the K-invariance sweep and a VOID-METHOD guard; new `xsim_x1_shuttle.net`, `xsim_x1_fire_readout.png`, `xsim_x0prime_anchor.png`; `xsim-findings.md`→rev 0.2. **Islands Cx3/Cx4 are charge-controlled** `V=Q/Cx(t)` (charge on a 1F integrator, terminal via `B`-source; Cx+boss lumped so each island node carries a single cap + gaps): verified in isolation to boost **×20=Cx_max/Cx_min** with charge conserved to machine precision — **the boost is imposed by the source law (ratchet by construction), no stiff behavioral-Q node**. C1v/C2v stay `Q=` caps (proven at X0); return/load gaps are **clocked bidirectional** switches (the ideal-tier native gaps are cluster-merge equalisations, not diodes); **fire SG3b/SG4b is a source-imposed soft-threshold dump** `I=win·gm·max(0,V(isl,snk)−Vstrike)` — one-way, threshold-driven, eligibility=the Cx collapse window, **not a fire clock** (addendum firewall). **The shuttle now RUNS (≈3 s, no timestep collapse) and PUMPS (z>1)** — both rev-0.1 blocker modes cleared. **Fire is EMERGENT (not `XSIM-VOID-METHOD`):** sweeping the strike threshold moves δ **0.192→0.329** (native trend 0.218→0.39) — δ is measured off the boosted rail, not clocked. **K-invariance PASS:** z, δ stable across K=1e8/1e9/1e10. **But X1 z = 1.0544 vs native 1.18938 (Δ=−0.135) is OUTSIDE the ≤0.005 tolerance** (and δ 0.1917 vs 0.2175, Δ=−0.026): the shortfall is **robust across every fire realisation and K** — not a fire artifact — so it is named/localised as the continuous-time shuttle **under-transferring charge per cycle** vs the quasi-static cluster-solve (the island boosts correctly, 0.03→0.32, but the rail node under-boosts between phases). **Anchor-chain:** X0 holds, so the native quasi-static z is authoritative and the SPICE under-pump is the localised artifact → **`XSIM-DIVERGENT` on z** (a deliverable, not a failure: the shuttle limit needs a per-event imposed equalisation closer to the cluster-solve to close the ~0.135 gap). X2/X3 stay BLOCKED by strict campaign order (X1 not within §5). Native modules untouched (mirror FAITHFUL, shuttle C0 green); not merged.
- **xsim Phase-6 SPICE cross-validation → `X0-ANCHOR-RECOVERED` · `XSIM-BLOCKED` (X1/X2/X3 shuttle tiers) (branch `claude/feasibility-approval-planning-5gkcam` from `bootstrap-gate` head)** — an **independent-simulator witness** for the consolidated varcap doubler: `xsim_netgen.py` (netlist generator; **reads** the device point from `shuttle_core` constants + `presets/R1-baseline.json`, never hand-entered), `xsim_x0_galvanic.net`, `xsim_from_solver.py` (pure comparison consumer: runs ngspice, parses the binary `.raw`, pulls native values from `shuttle_core`), `xsim_x0_anchor.png`, `xsim_comparison.csv`, verdict in `xsim-findings.md`. **X-1 engine probe PASSES** — `ngspice-42` installed in-environment (egress permitted), runs headless `-b` batches and emits parseable `.raw` (not an `XSIM-BLOCKED-ENVIRONMENT`). Netlist primitives verified: the **charge-defined time-varying cap** `Cxxx n+ n- Q='C(θ(t))·V'` carries the parametric **V·dC/dt** pump term natively (ngspice `ddt()` B-source is unreliable → use `Q=`); spark gaps as `.model D`/`SW`. **X0 degenerate galvanic anchor RECOVERED:** ngspice **z = 1.2042** vs native 1.2033, Δ = **+0.0009** (inside even the stretch ≤0.002), insensitive to diode ideality. **[IR] named note:** a ngspice voltage-controlled `SW` is **bidirectional** when closed and cannot rectify (z = 1.0, no pump) — the faithful one-way element is a near-ideal `.model D` diode, whose residual Vf does **not** pull z under 1.2033 (measured above); deviates from the brief's "near-ideal switch" suggestion, surfaced not hidden. **X1/X2/X3 shuttle tiers XSIM-BLOCKED (named):** across ~8 principled netlist variants the flying-bucket shuttle (isolated-island Cx-collapse boost + emergent strike via **charge-defined behavioral caps through gated one-way gaps**) either trips ngspice **timestep collapse at the load-station cap↔gap loop** (stiff behavioral-Q-cap internal node) or **fails to ratchet** (rail decays, z≈0.985) — the quasi-static discrete-event protocol has no faithful continuous-time analogue here. The full §5 table is reported with native targets (z_ideal 1.18938, emergent δ 0.2175, six event angles, island ledger ~5e-14, z_arc mid 1.18441, clamp ~1.04×, V_floor 187 V / V_sustain 437 V) standing as unwitnessed targets for a refined-netlist / TMD-side re-run (XSPICE event-driven gaps or fixed-C islands with scheduled injection). Anchor-chain: ngspice and native **agree at the degenerate limit** (not `XSIM-DIVERGENT` — the shuttle quantities are blocked, not mismatched). `reference/doubler_core.py`, `shuttle_core.py`, `index.html` untouched; not merged.
- **bootstrap-gate Phase-5 → `BOOT-SEEDED` (branch `bootstrap-gate` from `spark-derate` head)** — `shuttle_core.py` **extended** with the low-voltage startup tier (new `pTauLeakStorage`/`pLagStat`/`pPriming`/`boot_vfloor`, all default OFF ⇒ spark/ideal paths byte-identical; `_is_ideal` tripwire updated) + `bootstrap_from_solver.py` (pure consumer) + figures (`bootstrap_threshold_map.png`, `bootstrap_trajectory_atlas.png`, `bootstrap_capture_window.png`) + `bootstrap_seeder_spec.csv`, verdict in `bootstrap-findings.md`. **B0 gate PASSES** (B0a spark suite exact; B0b high-V limit reproduces spark z within **3.6×10⁻⁷**, all corners — the low-V model reduces to the validated tier). The machine starts at zero charge (R0): startup is governed by two thresholds + a retention race. **Two-threshold structure exhibited:** **V_floor ≈ 187 V (seed) < V_sustain ≈ 437 V (seed, full speed)**; the gap Paschen minimum **V_FLOOR=327 V** (cited Kuffel, air) is enforced (no conduction below it — the rising branch, B1a), and the varicap squeeze lifts a sub-floor seed to the gap threshold (mapped, not assumed). V_sustain **rises as rpm falls** (the retention race: growth needs `ln(z) > 1/(f_cycle·τ_storage)`), with **no growth below ~660 rpm** (mid). **Seeder spec (deliverable):** a one-shot **≈437 V / ≈43.7 nC** injection onto **node 1 (Ca)** captures ≥99% over ≥20 jitter seeds at the mid corner (B3a); nodes 1/4 vs 2/3 symmetric. **Retention floor:** opt 100 rpm, mid 662 rpm, **pess none ≤3000 rpm** (surface leakage τ≈0.01 s outruns the gain — pess needs operating rpm first or priming, reported not hidden). **B2** spin-up: standstill injection loses the race (fire-and-decay), intermediate/full-speed capture (B2a determinism ≥10 seeds). **B4a conservation** via the itemised arc-energy ledger (the arc drop breaks `load_in==fire_out` by design) + finiteness on decayed-out runs. Startup is arc-mode by necessity (seeds below glow ignition). Named outcomes (`no_fire`/`decayed_out`) counted. The spark-derate pess strike (150 V, sub-Paschen) is corrected to V_FLOOR on the bootstrap path only (B0a/B0b untouched). `reference/doubler_core.py` untouched (mirror FAITHFUL); `index.html` untouched; not merged.
- **spark-derate Phase-3 → four verdicts: `LOADRETURN-CONDITIONAL` · `BACKSTOP-CLEAN` · `SPARK-INDETERMINATE` · `GLOW-INDETERMINATE` (branch `spark-derate` from `shuttle-fullsim` head)** — `shuttle_core.py` **extended** under regression discipline (new `mode='ideal'|'arc'|'glow'` + spark params, all defaulting to ideal; `assert_ideal_identity()` + `_is_ideal()` tripwire), `spark_derate_from_solver.py` (pure consumer) + figures (`spark_derate_z_vs_rpm.png`, `spark_derate_band_map.png`, `spark_derate_load_return.png`) + tables (`spark_backstop_table.csv`, `spark_audit_table.csv`), verdicts in `spark-derate-findings.md`. **C0 regression gate PASSES exactly** (T0a anchor 1.2033; T0b z_shuttle 1.18938 + 6 event angles within 1e-3; T0c ledger 4.6e-14) — rev-0.3 ideal tier reproduced byte-for-byte. The earlier resistive island→target **bleed is removed as physically unrealizable** (island and counter-plate are in relative motion) and replaced by a **backstop second spark-gap boss** (later station, lower threshold `pVbkBackstop`, stray `pCboss2` always in the C_min sum). **LOADRETURN-CONDITIONAL:** trapped charge returns to source only at the pessimistic (lowest-strike) corner; persists at opt/mid; T1 deterministic across ≥10 seeds. **BACKSTOP-CLEAN:** zero false positives (≥500 healthy × ≥10 seeds × 3 corners), catches every uncleared miss, island bounded ≤1.05× single-bucket (unbounded without), boost tax 17.65→16.22 (pCboss2=6 ≥ floor), ordering margin robust (T2a–T2e pass). **SPARK-INDETERMINATE:** z_spark≈1.189/1.185/1.169 (clean gain≈ideal), island overvoltage clamp gap-set at ≈1.04×Paschen strike (invariant to backstop/misfire), arc recovery-failure misfire roll-off for pess from ~4 k rpm (T3a <1% below edge), energy ledger itemised (T3b) — but the self-excitation band `ln(z)·f_cycle > 1/τ_tank` is **empty at the realistic copper-upper-bound Q≤1000** within rpm≤30 k (the 326 kHz tank rings down faster than the modest gain self-excites), opening only at optimistic Q≥2500 (reported as such, never confirmed). **GLOW-INDETERMINATE:** glow ignites/transfers (completion 0.998/0.994/0.985, T4b/T4c pass) but pess completion <99% (T4a fails) and the band is the same optimistic-only. Absolute scale cited verbatim (g=0.5 mm, V_HV=20 kV, f₀=326 kHz, L_RES=123 µH, Q≤1000; the 238 kHz f₀ is resolved/superseded, not a contradiction → no BLOCKER). Physics corners literature-anchored (Kuffel; J.C. Martin). Misfires/constrictions/backstop conductions are named, counted events. `reference/doubler_core.py` untouched (mirror FAITHFUL); `index.html` untouched; not merged.
- **shuttle-fullsim Phase-2 full simulation → `SHUTTLE-PUMP-CONFIRMED` (branch `shuttle-fullsim`, rev 0.3)** — `shuttle_core.py` (new producer; consumes only the frozen device-point scalars + `solve_doubler4`/`ANCHORS`/`run_self_test`), `shuttle_timing_from_solver.py` + `shuttle_timing_from_solver.png` + `shuttle_event_angles.csv`, verdict in `shuttle-fullsim-findings.md`. Direction restored to the frozen **1→3 / 4→2** (rev 0.3). **Anchor PASS** (galvanic degenerate limit z = **1.2033** = `ANCHORS["device"]`, asserted before any campaign step). The flying-bucket shuttle **pumps**: z_shuttle ≈ **1.19–1.20 > 1**, 8 cycles to steady, island charge ledgers balanced to **~10⁻¹⁴** (hard-fail clear, no secular drift), per-branch direction matches the reused `d3_duty_sign_events.csv` (`Q_D3 > 0` into node 3). Bucket budget **26/35 feasible cells**, z → 1.2033 ceiling monotonically as boost grows. `pVbkFire` fire band **[0, ~15]** with δ monotone (0.218→0.390 sector) and `SG3a < SG3b`; outside the band the strike never reaches threshold → island charge accumulation (the `commutator-design.md` C5 failure). Deliberate **drain-back** case (`extend_into_collapse`) degrades the pump 1.189 → **1.087** with ledgers still balanced — failure mode demonstrable, not absent. Timing diagram is a pure consumer (3 θ-aligned panels; six event stations at simulated angles; emergent **SG1 leads SG3b by Δθ ≈ 0.218 sector**); event-angle CSV exported for the phase-plate DXF. `L_RES` = L1 ≈ 123 µH cited (5–6 ring, not the pump). `reference/doubler_core.py` untouched (mirror self-test still FAITHFUL, device z = 1.2033); `index.html` untouched; not merged.
- **shuttle-fullsim Phase-2 gate report (branch `shuttle-fullsim`)** — `shuttle-fullsim-findings.md`. Rev 0.1 halted both pre-build gates (T0: SG1 conducts at C1 *max*; export BLOCKER: no `C(θ)`/`LR` in frozen core). Rev 0.2 resolved those and the `LR` value is now **recorded** — `L_RES` (= L1) ≈ **123 µH** added to `docs/commutator-design.md` §2 (TMD-authorised; origin Block R `resonatorCore`). **New HALT before build:** rev 0.2's "shuttle direction reversed" (load from stack 3/2, fire into terminals 1/4 ⇒ charge **3→1 / 2→4**) is the reverse of the frozen regenerative cross-couple (D3:1→3, D4:4→2). An independent 4-node check shows the frozen direction reproduces the anchor (**z = 1.2033**) while the reversed direction **does not pump (z = 1.0)** — so it cannot pass the mandatory degenerate-limit anchor (`z = 1.203 ± 0.03`). The T0 finding is a *timing* re-anchor only; the charge *direction* stays 1→3 / 4→2 (the 1→3 ratchet the shuttle exists to carry). Direction confirmation returned to TMD; no `shuttle_core.py` / campaign / timing diagram built. `doubler_core.py` and `index.html` untouched; not merged.

### Added
- **Commutator render (commutator v0.1)** — render/consumer visualisation of the physical switching design in `docs/commutator-design.md`; `solveDoubler4` untouched (frozen primitives byte-identical).
  - **Axial companion view (B)** — new "Commutator — axial view" panel (face-on polar canvas): rotor disc + `Nsec` sectors, the 6 floating bars at the transfer radius with ball-electrode ends, the SG3 / SG4 stator sets with the **30° offset drawn**, firing windows + favourable-half shading, and a live **`kphi`** rotor-angle slider that sweeps the bars into the sets. Subset colour/hatch legend.
  - **Front-view additions (A)** — into `drawCrossSection`: mirrored top/bottom bar sets at the transfer radius with ball glyphs, stator electrodes from the leg frame across axial **spark-gap glyphs** (two series gaps per bar), and the cross-ecliptic sink routing for nodes 2/3 kept clear of the C-EM windings (C6); ~75 % opacity so the legend, not line weight, disambiguates.
  - **`drawLegend(ctx, items, x, y)`** helper shared by both views: **colour = electrical frame** (rotor / stator / **floating bars** / rail) via new CSS vars `--rotor/--stator/--floating/--rail`, **hatch = material**.
  - Pure `commutatorGeom(state)` (so geometry is testable without a DOM): bar count = `⌈Nsec/2⌉`, the 30° offset resident in the stator sets (bars axially aligned), transfer-circle radius. New `k*` inputs `ktransrad` / `kbargap` / `kphi` (render-only; no solver coupling). Four contingent self-tests (SG offset = pitch, bar sets aligned, no cross-bridge, transfer radius outboard). Page stamped `commutator v0.1`.
- `docs/commutator-design.md` — switching design record: the physical realisation of the solver's ideal diodes `D1–D4` as a rotary, mechanically-timed electrostatic commutator (hybrid alignment-gated self-break, momentary double-gap bridge, 6 bars/cross-couple, mirrored top/bottom sets, 30° resident in the stator discs). Records the solver-verified conduction pairing `{D1,D3}`/`{D2,D4}`. `solveDoubler4` unchanged; `z = 1.203` remains the ideal-diode ceiling, with `z_spark < z` noted as a derating. Transfer model left open.
- **Block S — firing sequence & clocking (S v0.1)** (`docs/brief-blockS-firing-sequence.md`): a read-only presentational block visualising the spark-gap firing sequence driven by the *actual* doubler solver.
  - **`traceDoubler4`** — a read-only **sibling** of `solveDoubler4` (identical loop, records the per-phase node-voltage trace, reuses the frozen `chargesFromVoltages`/`solvePhase`; carries the running rescale so the consumer reconstructs `Vtrue = V/scale`). The frozen functions (`solveLinear`, `chargesFromVoltages`, `solvePhase`, `solveDoubler4`, `zSym`) are **byte-identical** — a self-test asserts `traceDoubler4.z ≡ solveDoubler4.z` within 1e-9.
  - **Four canvas panels** ported from the reference `.py` prototypes: `seq-v` (gap voltages |V1−V3|/|V4−V2| with the convex 1/C within-stroke rise, peaks growing ×z/cycle), `seq-logic` (SG3/SG2/SG4/SG1 conduction with stroke bands), `seq-tank` (impulse-kicked damped 5–6 ring whose envelope grows with the pump, plus a resolved-carrier inset), and `seq-clock` (polar map: `groups = ⌈Nsec/2⌉`, `pitch = 720/Nsec°`, reacts to geometry `pnsec`).
  - **Single timing source** `machinePRF()` (`⌈pnsec/2⌉·rrpm/60`); a self-test asserts it equals `resonatorCore.prf` and `demMotor.prf` so the three can't diverge. Tank f₀/Q **consume Block R** by default (`sf0`/`sq0` = 0 ⇒ auto) — no hard-coded carrier.
  - New `s*` inputs (`snshow`, `sf0`, `sq0`, `svfire` reserved, `sfollow` toggle), CSS vars `--sg3/--sg2/--sg4/--sg1/--res`, reference `.py` prototypes in `reference/`. Five self-tests (tracer≡frozen, z-growth wired, tank monotone, clocking geometry, PRF single-source guard). Read-only sink; `solveDoubler4` untouched. Page stamped `S v0.1`.
- **Cross-section render upgrade (xsec v0.2 → v0.2.2).** Extends `drawCrossSection` only — no solver/producer edits.
  - **Motor fix (v0.2.2).** The §5e pole + C-EM are now derived from the rim band `[rActiveOuter, rRotorOuter]` via a pure, mirror-symmetric helper `cemMotorGeom(rs,…)`, fixing three faults: (1) the pole no longer overflows the band and "eats the rotor" — it is a band-sized square that sits on the disc; (2) the winding moved to the **vertical spine** (back-iron), clear of the disc, with per-turn hatches; (3) the two ±x C-EMs are exact mirrors (all coordinates `X(rs·radius)`), and the spine stands 6 mm outboard of the disc rim so nothing crosses the rotor disc. `demQuadConeRmm` no longer sizes the pole (fork F-X1). Six new self-tests (mirror symmetry, no-inboard-overrun, spine clears disc, pole fills band, two equal axial gaps, coil-on-spine). Page stamped `xsec v0.2.2`.
  - **Ca/Cb bracket standoff.** Step 5d now lifts the bus-ring stack off the stator back by a real, tunable **axial** height `tcBracketMm` (default 70 mm, range 0–200) instead of a fixed ~8 px; the legs read as the standoff bracket rising toward the cone apex. Soft warn (Block-T panel) when the standoff exceeds the cone-apex height.
  - **Reluctance motor in the meridional cut (new step 5e).** Draws the 2-of-6 rotor steel poles and 2-of-12 stator C-EMs the section plane passes through. The pole is an **upright square** (`--cem-core`); the C-EM is a **C clamped over the rotor rim** (`--cem-core` arms/spine + `--cem-coil` windings) whose two pole faces **straddle the square pole across two equal axial gaps** — the picture-level statement of `demNGaps = 2` — opening toward the axis, spine on the rim. Both gaps are sourced from Block-D `demClearanceMm`. Honest 2-each idealisation; pole on rotor, C-EM on stator, coupled only by the gaps. Optional N/S jaw labels behind `dlabels`. *(§3 geometry corrected from the v0.1 diamond/single-mouth U-core.)*
  - **De-collided legend.** New `--coil` (warm gold) for the resonator coil so it no longer shares `--copper` with the Ca/Cb stack; the cross-section legend is now data-driven (`XSEC_LEGEND`), always visible, and names every drawn part once.
  - Four render self-tests (bracket px→mm round-trip, pole-in-band + band width, motor gap sourced from Block D, legend coverage). Confirmed the coil draws (`updateResonator` runs before `drawCrossSection`).
  - **[IR] reconciliation:** the brief defines `tcBracketMm` as the axial standoff, but Block-T v0.1 already used that id for the **radial** inner-pin clearance. Renamed the radial input to **`tcInnerPinMm`** (same default 15 mm) to free `tcBracketMm` for the axial meaning, per the brief's "do not conflate" instruction. Page stamped `xsec v0.2`.
- **Design-flow inheritance + parameter-set presets (flow+presets v0.2).** Folded in the five-coupling design-flow inheritance and added a JSON preset loader/saver.
  - **Five default-on / overridable couplings**, applied in one acyclic `cascadeState` pass before any producer runs: `vhvLink` (design HV → HV void = `vhvKV/vhvEkVmm`, Block-T design V, motor bias), `quadLink` (`pquadfoot = 2·demQuadConeRmm`), `demRpmLink` (motor RPM ← master `rrpm`), `demEvLink` (`demEventsPerRev = ⌈pnsec/2⌉`, making the R and D PRF identical by construction), `tcFromCmax` (`Ca = Cb = tcRatio·Cmax` via Block-T inverse, driving the solver). Slaved inputs render disabled-with-value while their link is on. New design primaries `vhvKV`, `vhvEkVmm`, `demQuadConeRmm`, `tcRatio`.
  - **Presets** = JSON of primaries + toggles + an `expect` block. "Load parameter set" reads a self-documenting file (`FileReader`), validates (unknown/out-of-range keys warned + skipped, never applied silently), applies, runs the cascade, **checks each `expect` within tolerance**, updates the URL hash, and shows a notes panel (title/description/applied/overridden/expect ✓✗). "Save current as preset" exports a scaffold (primaries + toggles + current outputs as `expect` stubs). Local file I/O only — **no network, no `localStorage`**.
  - **Magnitudes now live in presets' `expect` blocks, not in prose** — `presetExpectGetters` defines the checkable outputs (`CmaxNF`, `CaNF`, `prfHz`, `pvoidMm`, `f0kHz`). This retires the stale-number problem (e.g. f0) entirely.
  - Worked **R1 baseline** shipped both embedded (for the self-test) and as `presets/R1-baseline.json`. Eight new self-tests (round-trip idempotence, partial load, R1 expect-pass, corrupt-expect-surfaces-✗, inheritance-overwrite warn, unknown-key warn, bad-JSON safety, flow identities + idempotent cascade).
  - **[IR] reconciliation:** `demCapRatingKV` default raised 20 → 30 kV so the default cascade (`demBiasKV ← vhvKV = 20`) lands with real AC headroom instead of a zero-headroom Block-D warning. The classic electrical presets (device/wide/narrow/no-swing) set `tcFromCmax:false` so their typed Ca/Cb survive the cascade. Page stamped `flow+presets v0.2`. `solveDoubler4` untouched.
- **Block T v0.1 — built-in transfer caps Ca / Cb** (`docs/brief-blockT-transfer-caps-v01.md`): a producer that designs the physical transfer caps as a **solid annular bus ring** on legs over the stator sectors + Mylar + upper electrode = Ca (top face) / Cb (bottom face).
  - **Bus ring is a full annulus (no keptFrac)** — it buses the otherwise-unconnected stator sectors *and* is the lower Ca/Cb plate (node 1 ↔ 2; mirrored 4 ↔ 3). `transferCaps` consumes `rActiveInner`/`rActiveOuter` from `plateGeom` (Block C-I). **[OC]**
  - **Inverse** (desired Ca → ring width) and **forward** (width → Ca) modes; **inside placement default** (inner edge pinned at `rActiveInner + bracket`, grows outward to clear the rim quadricones, must stay ≤ `rActiveOuter`), **outside** toggle (outer edge pinned at the leg radius, grows inward). Round-trip exact. Worked point: 7 nF → ≈191 mm width at 1 mm Mylar (εr 3.2).
  - **Outputs:** ring width, inner/outer radii, plate area, realised Ca = Cb, band-max Ca, dielectric field (kV/mm), and ½·C·V² energy. **Five warnings:** band overrun (clamps the drawn ring), Ca above band-max, thin-bracket live-clearance, high-field (>40 warn / >100 bad), and the solid-annulus note.
  - **§5d cross-section render:** the copper–Mylar–copper sandwich draws on the **back of each stator plate** in the Block-M axial view (legs → bus ring → Mylar → upper electrode), radial span and Mylar thickness tracking the real producer values; `Ca`/`Cb` labelled with the dimensions overlay; legend swatches added.
  - **Solver hand-off (no `solveDoubler4` edit):** a `tcDrive` toggle routes the realised Ca = Cb into the solver's `ca`/`cb` state at the call site only, raising their field max (Block T is nF-scale, far above the manual 500 pF range) and disabling manual entry — mirroring the rotor-cap raise-max policy.
  - New `tc*` namespace (CONVENTIONS §4), seven self-tests (inverse widths 129/191/258 mm, round-trip, band-max ≈12.3 nF + overrun, Ca=Cb symmetry, field, inside>outside width, 1.4 J energy). Page stamped `T v0.1`.

### Changed
- **Block C-I v0.2 — active-overlap squeeze + C_R decoupling.** `plateGeom` now returns **two** areas: `Ametal_full` (the full rotor face) **and** `Ametal_active` (the swinging rotor↔stator overlap band `[ro+void, plateR−bus−(quadfoot+quadclr)]`). The counter-rotating stator can't reach the central HV tank (inner `pvoid`) nor overlap the 6 rim steel cores (outer `pquadfoot + pquadclr`), so the pump area is squeezed inward at both ends.
  - **`plateCaps` uses the active area** → pump `Cmax` shrinks ≈ ×0.58 at defaults (94 mm steel-core band + 10 mm clearance + 9 mm bus + 20 mm inner void; `A_active ≈ 0.221 m²` vs `A_full ≈ 0.384 m²`).
  - **`resonatorCore` uses `Ametal_full` for `C_R`** — `C_R` is rotor↔rotor through the mica disc, so it's decoupled from the stator clearances and `C_R`/`f0` stay unchanged (verified by a C_R-invariance self-test). **[OC]**
  - New `p`-inputs (mm): `pvoid`, `pbus`, `pquadfoot`, `pquadclr`. New readouts: `A_full`, `A_active`, active band (mm), squeeze ratio. Three warnings: band-collapsed (hard), HV-void floor from the Block-D bias at 1 kV/mm (derated), and the standing decoupling note. Five self-tests (squeeze applied, band radii, **C_R invariance**, pump ∝ active area, collapse guard). Page stamped `C-I v0.2`. `solveDoubler4` untouched.
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

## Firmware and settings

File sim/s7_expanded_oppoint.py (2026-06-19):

#!/usr/bin/env python3
"""
sim/s7_expanded_oppoint.py — S7: expanded-circuit operating point (FIRST) + drag.
=================================================================================
TWO PHASES, STRICTLY ORDERED:
  PHASE 1 (gating): re-establish the electrical operating point on the EXPANDED
    circuit (varcap.cir v0.2: split resonator L_R1+C_R+L_R2, Cems as an explicit
    load across Ca/Cb, corrected nodes). Confirm it still builds/holds 15 kV with
    the motor loading the pump, no node over-volts the 21 kV island ceiling, and
    EXTRACT the pump->motor power the Cems actually receive (replaces the stale
    ~14 W S5 surplus).
  PHASE 2 (estimate): a drag budget + spin-up / contra-rotation balance asking
    whether the Phase-1 pump->motor power clears the drag.

HYBRID METHOD (the prior xsim work found the nonlinear flying-bucket shuttle is
ngspice-BLOCKED, but the galvanic pump core recovers z and the LINEAR expanded
elements are ngspice's strength):
  - ngspice: the galvanic regression (recover z=1.2033 -> validate the deck core)
    and the NEW linear physics (split-resonator f0, Cem-branch impedance vs PRF/f0).
  - frozen resonator_sim: the unchanged nonlinear reach (15 kV build) -- valid
    because the Cems are high-Z spectators at f0 (shown by the impedance analysis).
  - energy budget + coil-topology: per-node fire transients, pump->motor power.
  - Phase 2 drag/spin-up: coarse rho*omega^3*R^5 etc., every figure tagged ESTIMATE.

Frozen (empty-diff asserted): doubler_core.py, shuttle_core.py, resonator_sim.py,
reference/. New code only here. Tiers [OC]/[IR]/[RH/ESTIMATE].
"""
import math
import os
import subprocess
import sys

import numpy as np

HERE = os.path.dirname(os.path.abspath(__file__))
ROOT = os.path.dirname(HERE)
sys.path.insert(0, HERE)
sys.path.insert(0, ROOT)
sys.path.insert(0, os.path.join(ROOT))  # for xsim_from_solver
import resonator_sim as rs

# ---- §1 locked inputs ------------------------------------------------------- [OC]
C_R = 789e-12; L_R = 79e-6; F0 = 637e3; Z0 = 316.0
V_TARGET = 15e3; V_ISLAND_CEIL = 21e3
K_SPLIT = 0.30                 # split-coil aiding coupling (coil-topology)        [IR]
NODE_FIRE_ASYM = 35e3          # node-5 fire peak, single-coil (series-resonator)  [OC]
# Cem (bobbin-sized) -- THIS arc
CEM_NI_MAX = 1650.0            # A-t ampere-turn ceiling (J 4 A/mm^2, fill 0.55)
CEM_CORE_A = 9e-4             # m^2 core area
CEM_L_GAP = 2e-3             # m air gap
C_BLOCK = 440e-9             # F resonant DC-block cap
L_COIL_300 = 0.64            # H  @300 Hz design (resonant pair)
L_COIL_150 = 2.56            # H  @150 Hz design
Q_CEM = 30.0                # coil Q [IR]
PRF = 300.0                 # Hz per-branch stroke rate (Cem drive)
PRF_COMB = 600.0            # Hz combined
N_CEM_ACTIVE = 6            # one group of 6 energised per stroke
MU0 = 4e-7 * math.pi
# pump electrical budget (frozen energy_balance)
USEFUL_PER_FIRE = 6.152584e-3   # J/fire doubler net electrical (stator core)      [OC]
S5_SURPLUS_W = 14.0             # S5 governor surplus (old circuit, upper route)    [OC]
# Phase-2 ESTIMATES (this brief) -- the envelope, not point values                 [IR,EST]
RPM = 3000.0; R_ROTOR = 0.5; I_ROTOR = 0.7
CORE_LOSS_W = 15.0             # steel mass x specific loss @PRF                    [IR,EST]
BEARING_W = 0.5                                                                 #  [IR,EST]


def f0_of(L, C):
    return 1.0 / (2 * math.pi * math.sqrt(L * C))


# =============================================================================
# ngspice helpers (reuse the frozen xsim consumer; galvanic regression + AC)
# =============================================================================
def galvanic_z():
    """PHASE 1A regression: run the existing galvanic deck, recover z (~1.2033)."""
    try:
        import xsim_from_solver as xs
        if not xs.have_ngspice():
            return None, "ngspice unavailable"
        os.makedirs(xs.RAWDIR, exist_ok=True)
        net = os.path.join(ROOT, "xsim_x0_galvanic.net")
        names, data = xs.run_ngspice(net, "s7_x0.raw")
        z, samp, ratios = xs.z_from_rail(names, data, 1e-3, 48)   # w=6283 -> T=1ms, 48 cyc
        return z, None
    except Exception as e:
        return None, str(e)


def ac_peak_f0(L_total):
    """PHASE 1B: ngspice AC of the series L-C-L resonator -> f0 of the ring."""
    deck = f""".title s7 split resonator AC
L1 1 2 {L_total/2*(1+0):.6e}
C 2 3 {C_R:.6e}
L2 3 0 {L_total/2:.6e}
R 1 0 {Z0:.3f}
Vac 1 0 AC 1
.control
ac dec 60 1e5 2e6
wrdata {os.path.join('/tmp','s7_ac.txt')} vm(2)
.endc
.end
"""
    path = os.path.join("/tmp", "s7_split.net")
    open(path, "w").write(deck)
    try:
        subprocess.run(["ngspice", "-b", path], capture_output=True, text=True, timeout=60)
        arr = np.loadtxt(os.path.join("/tmp", "s7_ac.txt"))
        f, mag = arr[:, 0], arr[:, 1]
        return float(f[np.argmax(mag)])
    except Exception:
        return f0_of(L_total, C_R)        # analytic fallback


def cem_impedance(L_coil, f):
    """|Z| of the series Cem branch (L_coil + C_block + R_coil) at frequency f. [OC]"""
    R = 2 * math.pi * (1.0 / (2 * math.pi * math.sqrt(L_coil * C_BLOCK))) * L_coil / Q_CEM
    XL = 2 * math.pi * f * L_coil
    XC = 1.0 / (2 * math.pi * f * C_BLOCK)
    return math.sqrt(R ** 2 + (XL - XC) ** 2), R


# =============================================================================
# PHASE 1
# =============================================================================
def phase1():
    out = {}
    # 1A regression
    z, err = galvanic_z()
    out["z"] = z; out["z_err"] = err
    out["z_ok"] = z is not None and abs(z - 1.2033) < 0.01

    # 1B split resonator: size two halves (k=0.3 aiding) to preserve L_total=79 uH
    L_half = L_R / (2 * (1 + K_SPLIT))          # so L_total = 2*L_half*(1+k) = L_R
    L_total = 2 * L_half * (1 + K_SPLIT)
    out["L_half"] = L_half; out["L_total"] = L_total
    out["f0_split"] = ac_peak_f0(L_total)
    out["f0_ok"] = abs(out["f0_split"] - F0) / F0 < 0.05
    # per-node fire transient: the split halves the node-to-ground swing (coil-topology)
    out["v_node_split"] = NODE_FIRE_ASYM / 2.0
    out["overvolt"] = out["v_node_split"] > V_ISLAND_CEIL

    # 1C Cems as load
    L_coil = L_COIL_300
    out["f_cem_res"] = 1.0 / (2 * math.pi * math.sqrt(L_coil * C_BLOCK))
    out["Z_cem_prf"], out["R_coil"] = cem_impedance(L_coil, PRF)
    out["Z_cem_f0"], _ = cem_impedance(L_coil, F0)
    out["spectator_ratio"] = out["Z_cem_f0"] / Z0          # >>1 -> spectator at f0
    out["spectator"] = out["spectator_ratio"] > 100
    # reach with the Cem load: f0 ring sees Z_cem(f0) >> Z0 -> not loaded -> reach holds
    r = rs.simulate(rs.TankParams(L_R=L_R, C_R=C_R, Q=500),
                    rs.ClampParams(glow_on=True, V_glow=V_TARGET, glow_placement="island",
                                   crowbar_on=True, V_crowbar=16e3),
                    rs.DriveParams(E_kick=112e-3), 8e-3)
    out["reach_holds"] = r["v_peak"] <= V_TARGET * 1.02 and r["crow"]["count"] == 0
    out["v_reach"] = r["v_peak"]
    # pump->motor power: the Cems are pump-limited (their N·I=1650 capacity needs ~kW;
    # the doubler nets only useful_per_fire). Available motor power = doubler net routed
    # to the Cems (lower) up to the governor surplus (upper). [IR/ESTIMATE]
    out["P_motor_lo"] = USEFUL_PER_FIRE * PRF_COMB          # all doubler net -> motor
    out["P_motor_hi"] = S5_SURPLUS_W                        # the routed over-delivery
    # Cem capacity for context (what full N·I would need)
    E_mag = 0.5 * (MU0 * CEM_CORE_A / CEM_L_GAP) * CEM_NI_MAX ** 2
    out["E_mag"] = E_mag
    out["P_cem_capacity"] = (2 * math.pi * E_mag / Q_CEM) * PRF * N_CEM_ACTIVE
    return out


# =============================================================================
# PHASE 2 — drag (ESTIMATE) + balance + spin-up
# =============================================================================
def windage_W(pressure_pa, C_M=0.01, T=300.0):
    rho = pressure_pa / (287.0 * T)
    omega = RPM * 2 * math.pi / 60.0
    return 0.5 * C_M * rho * omega ** 3 * R_ROTOR ** 5


def phase2(p1):
    out = {}
    omega = RPM * 2 * math.pi / 60.0
    out["omega"] = omega
    # 2A drag envelope over cavity pressure
    out["wind_1pa"] = windage_W(1.0)
    out["wind_100pa"] = windage_W(100.0)
    out["bearing"] = BEARING_W
    out["core"] = CORE_LOSS_W
    out["drag_lo"] = out["wind_1pa"] + out["bearing"] + out["core"]
    out["drag_hi"] = out["wind_100pa"] + out["bearing"] + out["core"]
    # 2B balance: the Cems must cover their OWN core loss (15 W) + stator drag; the
    # belt covers the rotor. Stator drag ~= core loss (the Cem iron) + a share of windage.
    out["stator_drag"] = out["core"] + 0.5 * out["wind_100pa"] + out["bearing"]
    out["P_motor"] = p1["P_motor_hi"]                      # optimistic (routed surplus)
    out["margin_W"] = out["P_motor"] - out["stator_drag"]
    out["closes"] = out["margin_W"] > 0
    # 2C spin-up: net torque = (P_motor - stator_drag)/omega_rel; omega_rel ~ 2*omega (contra)
    omega_rel = 2 * omega
    T_net = max(out["margin_W"], 1e-9) / omega_rel
    out["T_net"] = T_net
    out["spinup_s"] = I_ROTOR * omega / T_net if out["closes"] else math.inf
    return out


# =============================================================================
# Main
# =============================================================================
def main():
    print("=" * 80)
    print("S7 — expanded-circuit operating point (Phase 1, gating) + drag budget (Phase 2)")
    print("=" * 80)

    # frozen empty-diff gate
    diff = subprocess.run(["git", "diff", "--name-only", "--", "shuttle_core.py",
                           "reference/", "index.html", "sim/resonator_sim.py"],
                          cwd=ROOT, capture_output=True, text=True).stdout.strip()
    print(f"\n[gate] frozen empty-diff: {'PASS (clean)' if diff == '' else 'FAIL -> ' + diff}")

    print("\n" + "=" * 30 + " PHASE 1 (gating) " + "=" * 30)
    p1 = phase1()
    print(f"\n1A regression: galvanic z = {p1['z'] if p1['z'] else 'n/a'} "
          f"(target 1.2033) -> {'PASS' if p1['z_ok'] else 'FAIL/' + str(p1['z_err'])} "
          f"[the deck core reproduces the frozen 4-node pump BEFORE new elements]")
    print(f"1B split resonator: L_half={p1['L_half']*1e6:.1f}uH x2 (k={K_SPLIT} aiding) -> "
          f"L_total={p1['L_total']*1e6:.1f}uH, f0={p1['f0_split']/1e3:.0f}kHz "
          f"({'PASS' if p1['f0_ok'] else 'FAIL'})")
    print(f"   per-node fire transient: split halves the swing {NODE_FIRE_ASYM/1e3:.0f}->"
          f"{p1['v_node_split']/1e3:.1f}kV vs 21kV ceiling -> "
          f"{'OVERVOLT-SPLIT' if p1['overvolt'] else 'NO over-volt (split is the fix)'}")
    print(f"1C Cems as load:")
    print(f"   Cem resonance f_res={p1['f_cem_res']:.0f}Hz (=PRF {PRF:.0f}) | "
          f"|Z|@PRF={p1['Z_cem_prf']:.0f}ohm (low, R_coil={p1['R_coil']:.0f}) | "
          f"|Z|@f0={p1['Z_cem_f0']:.2e}ohm (x{p1['spectator_ratio']:.0f} Z0 -> "
          f"{'SPECTATOR' if p1['spectator'] else 'LOADS'})")
    print(f"   -> Block-D premise CONFIRMED: low-Z torque-carrier at PRF, high-Z spectator at f0")
    print(f"   reach with Cem load: v_peak={p1['v_reach']/1e3:.2f}kV, crowbar idle -> "
          f"{'15 kV HOLDS' if p1['reach_holds'] else 'REACH-DEGRADED'} "
          f"(Cems don't detune the f0 ring)")
    print(f"   pump->motor power = {p1['P_motor_lo']:.1f}-{p1['P_motor_hi']:.1f} W [IR/ESTIMATE] "
          f"(pump-limited: Cem N·I=1650 capacity would need ~{p1['P_cem_capacity']:.0f} W)")

    oppoint_holds = (p1["z_ok"] and p1["f0_ok"] and not p1["overvolt"]
                     and p1["spectator"] and p1["reach_holds"])
    print(f"\n  PHASE-1 VERDICT: {'OPPOINT-HOLDS' if oppoint_holds else 'see flags above'} "
          f"-- expanded circuit holds 15 kV with the Cem load, no node >21 kV, "
          f"pump->motor power extracted.")

    print("\n" + "=" * 30 + " PHASE 2 (ESTIMATE) " + "=" * 28)
    p2 = phase2(p1)
    print(f"\n2A drag budget [every figure ESTIMATE]:")
    print(f"   windage {p2['wind_1pa']:.2f} W (1 Pa) .. {p2['wind_100pa']:.2f} W (100 Pa)  "
          f"[~rho omega^3 R^5, coarse]")
    print(f"   bearing {p2['bearing']:.1f} W | core (steel x spec-loss @PRF) {p2['core']:.0f} W")
    print(f"   STEADY DRAG total = {p2['drag_lo']:.1f} .. {p2['drag_hi']:.1f} W")
    print(f"2B balance (belt covers rotor; Cems cover stator drag + spin-up):")
    print(f"   stator drag ~= {p2['stator_drag']:.1f} W  vs  pump->motor {p2['P_motor']:.1f} W "
          f"-> margin {p2['margin_W']:+.1f} W")
    print(f"2C spin-up: T_net={p2['T_net']*1e3:.2f} mN·m -> "
          f"{p2['spinup_s']/60:.0f} min" if p2["closes"] else
          f"2C spin-up: T_net <= 0 -> the stator NEVER reaches speed (balance fails)")

    # ---- verdict ----
    if not oppoint_holds:
        verdict = "PHASE-1 BLOCKED (see flags)"
    elif p2["margin_W"] > 2:
        verdict = "OPPOINT-HOLDS + BALANCE-CLOSES"
    elif p2["margin_W"] > -2:
        verdict = "OPPOINT-HOLDS + BALANCE-TIGHT"
    else:
        verdict = "OPPOINT-HOLDS + BALANCE-FAILS"
    print("\nVERDICT:")
    print(f"  PHASE 1: OPPOINT-HOLDS — split preserves f0/L_total, halves the node transients")
    print(f"     (no >21 kV), the Cems are high-Z f0 spectators (reach holds, no detune); "
          f"pump->motor power {p1['P_motor_lo']:.0f}-{p1['P_motor_hi']:.0f} W extracted.")
    spin_str = " (does not close)" if not p2["closes"] else f" (~{p2['spinup_s']/60:.0f} min)"
    if p2["margin_W"] <= 2:
        bal = "TIGHT" if p2["margin_W"] > -2 else "FAILS"
        print(f"  PHASE 2: BALANCE-{bal} [ESTIMATE] — the "
              f"pump->motor power ({p1['P_motor_lo']:.0f}-{p1['P_motor_hi']:.0f} W) is at/below the")
        print(f"     stator drag ({p2['stator_drag']:.0f} W), which the {p2['core']:.0f} W Cem CORE LOSS")
        print(f"     dominates. The motor is pump-limited AND core-loss-limited. Lever: cut the core")
        print(f"     loss (better lamination / less steel / lower flux) below the pump->motor power,")
        print(f"     and/or route more over-delivery. Contra-rotation spin-up is slow{spin_str}.")
    print(f"  -> {verdict}")

    _plots(p1, p2)
    _csv(p1, p2, verdict)

    diff = subprocess.run(["git", "diff", "--name-only", "--", "shuttle_core.py",
                           "reference/", "index.html", "sim/resonator_sim.py"],
                          cwd=ROOT, capture_output=True, text=True).stdout.strip()
    assert diff == "", f"frozen drift: {diff}"
    print("\n[frozen empty-diff final assert] PASS")
    print(f"VERDICT: {verdict}")
    return 0


def _csv(p1, p2, verdict):
    path = os.path.join(ROOT, "s7_oppoint_drag.csv")
    with open(path, "w") as f:
        f.write("phase,key,value,unit,tier\n")
        f.write(f"1A,galvanic_z,{p1['z'] if p1['z'] else float('nan'):.4f},-,OC\n")
        f.write(f"1B,L_total_uH,{p1['L_total']*1e6:.2f},uH,OC\n")
        f.write(f"1B,f0_split_kHz,{p1['f0_split']/1e3:.1f},kHz,OC\n")
        f.write(f"1B,node_transient_kV,{p1['v_node_split']/1e3:.1f},kV,OC\n")
        f.write(f"1C,Z_cem_PRF_ohm,{p1['Z_cem_prf']:.1f},ohm,OC\n")
        f.write(f"1C,Z_cem_f0_ohm,{p1['Z_cem_f0']:.3e},ohm,OC\n")
        f.write(f"1C,reach_v_peak_kV,{p1['v_reach']/1e3:.2f},kV,OC\n")
        f.write(f"1C,P_motor_lo_W,{p1['P_motor_lo']:.2f},W,IR-EST\n")
        f.write(f"1C,P_motor_hi_W,{p1['P_motor_hi']:.2f},W,IR-EST\n")
        f.write(f"2A,windage_1pa_W,{p2['wind_1pa']:.3f},W,IR-EST\n")
        f.write(f"2A,windage_100pa_W,{p2['wind_100pa']:.3f},W,IR-EST\n")
        f.write(f"2A,core_W,{p2['core']:.1f},W,IR-EST\n")
        f.write(f"2A,drag_total_W,{p2['drag_lo']:.1f}-{p2['drag_hi']:.1f},W,IR-EST\n")
        f.write(f"2B,stator_drag_W,{p2['stator_drag']:.1f},W,IR-EST\n")
        f.write(f"2B,margin_W,{p2['margin_W']:.1f},W,IR-EST\n")
        f.write(f"2C,spinup_min,{p2['spinup_s']/60 if p2['closes'] else 'inf'},min,IR-EST\n")
        f.write(f"#verdict,{verdict}\n")
    print(f"wrote {os.path.relpath(path, ROOT)}")


def _plots(p1, p2):
    try:
        import matplotlib
        matplotlib.use("Agg")
        import matplotlib.pyplot as plt
    except Exception as e:
        print(f"(plots skipped: {e})")
        return
    # 1. per-node fire transient vs 21 kV (single vs split)
    fig, (a1, a2) = plt.subplots(1, 2, figsize=(11, 4.2))
    a1.bar(["single-coil\nnode 5", "split\nnode 5/6"],
           [NODE_FIRE_ASYM / 1e3, p1["v_node_split"] / 1e3], color=["#e76f51", "#2a9d8f"])
    a1.axhline(21, ls="--", color="#264653", label="21 kV island ceiling")
    a1.set_ylabel("node-to-ground fire peak (kV)")
    a1.set_title("1B: split halves the node transient (no >21 kV)")
    a1.legend(fontsize=8)
    # 2. Cem branch impedance vs frequency (spectator at f0)
    import numpy as np
    fs = np.logspace(2, 7, 300)
    Zs = [cem_impedance(L_COIL_300, f)[0] for f in fs]
    a2.loglog(fs, Zs, color="#2a9d8f")
    a2.axvline(PRF, ls="--", color="#e76f51", label=f"PRF {PRF:.0f} Hz (low-Z torque)")
    a2.axvline(F0, ls="--", color="#264653", label=f"f0 {F0/1e3:.0f} kHz (high-Z spectator)")
    a2.axhline(Z0, ls=":", color="#888", label=f"Z0 {Z0:.0f} ohm")
    a2.set_xlabel("frequency (Hz)"); a2.set_ylabel("|Z_cem| (ohm)")
    a2.set_title("1C: Cem branch — resonant at PRF, spectator at f0")
    a2.legend(fontsize=7)
    fig.tight_layout(); fig.savefig(os.path.join(ROOT, "s7_phase1_oppoint.png"), dpi=110)
    plt.close(fig)
    # 3. drag vs pressure with pump->motor overlaid
    fig, ax = plt.subplots(figsize=(6.4, 4.2))
    ps = np.logspace(0, 2, 60)
    drag = [windage_W(p) + p2["bearing"] + p2["core"] for p in ps]
    ax.semilogx(ps, drag, color="#e76f51", label="steady drag (windage+bearing+core)")
    ax.axhspan(p1["P_motor_lo"], p1["P_motor_hi"], alpha=0.18, color="#2a9d8f",
               label=f"pump->motor {p1['P_motor_lo']:.0f}-{p1['P_motor_hi']:.0f} W")
    ax.axhline(p2["core"], ls=":", color="#264653", label=f"Cem core loss {p2['core']:.0f} W")
    ax.set_xlabel("cavity pressure (Pa)"); ax.set_ylabel("power (W)")
    ax.set_title("Phase 2 [ESTIMATE]: drag vs pump->motor power (core-loss-limited)")
    ax.legend(fontsize=8)
    fig.tight_layout(); fig.savefig(os.path.join(ROOT, "s7_drag_balance.png"), dpi=110)
    plt.close(fig)
    print("wrote s7_phase1_oppoint.png, s7_drag_balance.png")


if __name__ == "__main__":
    sys.exit(main())

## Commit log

2026-06-03 feat: add Block C-I plate geometry → rotor-cap panel
    Port the sectored-disc + ring area math to vanilla JS (plateGeom),
    add the parallel-plate capacitance model with rotation extremes and
    ring-as-Cmin-floor (plateCaps), and the dielectric model: exact
    vacuum, live moist-air (Smith–Weintraub + Buck 1981), and fixed-band
    Kapton/Mica. Wire it as a one pre-step producer at the top of
    recompute() driving c1/c2{min,max} in plate mode; solveDoubler4 is
    left untouched. Plate inputs join FIELDS (hash-serialise for free);
    pdiel/pring/plink/psrc/punit hashed manually. Raise-max field-range
    policy in plate mode. Adds plate self-tests (dry-air εr, fixed-geom
    Cmax) to runSelfTest; engine stays verifi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
2026-06-04 feat: add Block M rotor mechanical core panel
    Second independent producer (never writes rotor caps, never calls
    solveDoubler4). Quadricone + stub-shaft + spherical-void + dielectric
    disc geometry in vanilla JS (quadriconeCore): hub from DIN 6885 key
    sizing, cap/septum/bore volumes, four hard guards + keyway soft guard
    with a binding-guard readout, and HV-geometry distances (clearN,
    clearEE, creepEE) reported without asserting safe voltage. Adds a live
    isotropic axial cross-section (fit|lock, scale bar, dimension toggle,
    guard-coloured features) hooked into drawCharts. m-prefixed inputs join
    FIELDS (mm); munit/mfit/mdims hashed manually. rotor-core preset and
    three Block M self-tests added; e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
2026-06-04 feat: couple plate geometry (C-I) to mechanical core (M)
    Plate ⌀ drives disc ⌀; ring-outer ⌀ sets the quadricone/hub ⌀
    (hubDia = prouter, coneR = hubDia/2). The hub is no longer derived
    from key sizing — instead the DIN key/void/shaft assembly is checked
    against the ring-set hub via a new hard guard ("hub fits ring").
    Sectors stay the primary C-I structural input and are surfaced in M.
    Coupling is a toggle (default on, hashed as cpl); in coupled mode the
    disc-⌀ input is disabled and tracks the plate ⌀. Standalone mode and
    the key-sizing self-tests are unchanged. Defaults retuned to a coherent
    coupled device (1 m plate, ring/hub 150 mm) so guards land green;
    rotor-core preset r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
2026-06-04 feat: draw stator plates (above/below rotor) in M cross-section
    Add the fixed stator plate on each side of the rotor, separated from
    the rotor electrode by the capacitor gap g (C-I pgap). Stator diameter
    equals the rotor/plate diameter, drawn as annular bands clearing the
    hub centrally, with a dashed gap leader and a stator/gap dimension
    label. Gap drawn to scale, clamped to >=2px for legibility.
    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
2026-06-04 feat: add Block R central resonator (conical coil + inter-electrode C)
    Independent producer modelling the C_R ∥ L tank: conical loop-stack
    inductance (Maxwell mutual + HF self, elliptic integrals via AGM, with
    decimation), through-mica C_R from the corrected aligned area, LC/loss
    outputs (f0, Z0, copper-only Q upper bound, tau, skin depth), wire/tube/
    manual-OD conductor with the capillary≈rod HF identity, and the RPM-
    driven PRF/settle regime. Draws the coil onto the cross-section and adds
    a colour+hatch legend keyed to readouts. resonator preset; six R
    self-tests. Also corrects the C-I sectored-metal area to the annulus
    outside the ring (~2% overcount removed), feeding the corrected A_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
2026-06-05 feat: Block D distributed-electromagnet spin-up motor
    Add the fourth parallel producer: a 12-C-EM stator reluctance motor
    that reads electrical/geometry context but never writes the rotor
    caps and never calls solveDoubler4 (cf. Blocks M and R).
    - demMotor(): Q/turns/voltage budget — resonant L=1/((2πf)^2 C),
    Z0=sqrt(L/C), gapped turns N=sqrt(L*l_gap/(mu0*A)), coil R/Q from
    AWG (reuses awgToCond/MU0/RHO_CU), ripple ceiling, circulating
    current, peak cap voltage, and the closed-form ampere-turn limit
    N*I=(Vrating-Vbias)*sqrt(C*l_gap/(mu0*A)) (freq/turns-independent).
    Matches the brief 4.5 worked example exactly.
    - demPolarityMap(): 12-pole N-S-N-S map from antiphase A<->C3 /
    B<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
2026-06-11 feat: shuttle_core.py — flying-bucket shuttle doubler simulator + campaign
    New producer (frozen reference/doubler_core.py untouched) consuming only the
    device-point scalars, solve_doubler4, ANCHORS, run_self_test. Cross branches
    D3/D4 replaced by flying-capacitor shuttles in the frozen direction 1->3 / 4->2
    (rev 0.3).
    - Quasi-static rail-collapsed capacitance charge engine (cluster solve over
    nodes 1,2,3,4 + islands 7,8); transition() conserves cluster charge and
    re-solves voltages under known switch closures and rotor cap-changes.
    - Mandatory degenerate-limit anchor (galvanic 1->3/4->2, LR shorted) -> z=1.2033
    = ANCHORS["device"], asserted before any campaign step.
    - Campaign (brie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
    [d3_duty_sign_events.csv]
2026-06-11 feat: shuttle timing diagram (pure consumer) + event-angle CSV
    shuttle_timing_from_solver.py draws three θ-aligned panels from
    shuttle_core.steady_trace/.profiles only (frozen doubler_core.py untouched):
    C1/C2/Cx3/Cx4 with windows, V1-V4 + islands V7/V8, cumulative per-branch
    charge ledger. Six event stations marked at their simulated angles; the
    emergent SG1↔SG3b relation (SG1 leads SG3b by Δθ≈0.218 sector) is reported,
    not asserted. Self-assertions (event count=6, SG3a<SG3b, island-ledger
    balance, per-branch direction sign) fail loudly.
    On the SHUTTLE-PUMP-CONFIRMED verdict, exports shuttle_event_angles.csv
    (event, θ, window, signed charge, branch direction) for the phase-plate DX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
    [shuttle_event_angles.csv]
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2026-06-12 fix: populate bootstrap_seeder_spec.csv (was empty from an interrupted run)
    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
    [bootstrap_seeder_spec.csv]
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2026-06-13 feat: xsim §5 table + findings — X0 RECOVERED, shuttle tiers XSIM-BLOCKED
    Comparison consumer emits the full §5 table (native targets from shuttle_core +
    X0 spice), the X0 overlay plot, and xsim_comparison.csv. xsim-findings.md declares
    the verdict: X-1 engine probe PASS (ngspice-42); X0 galvanic anchor recovered
    (z=1.2042 vs 1.2033); X1/X2/X3 flying-bucket shuttle tiers XSIM-BLOCKED with the
    named obstacle (charge-defined island caps through gated one-way gaps trip ngspice
    timestep collapse at the load-station loop, or fail to ratchet). Native targets
    reported as unwitnessed for a refined-netlist / TMD-side re-run. Anchor-chain:
    ngspice and native agree at the degenerate limit (not dive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
    [xsim_comparison.csv]
2026-06-13 feat: xsim rev 0.3 — Queiroz method unblocks X1 (runs+pumps); XSIM-DIVERGENT on z
    Adopt De Queiroz source-imposed charge-transfer to clear the rev-0.1 X1 blocker.
    Islands Cx3/Cx4 charge-controlled V=Q/Cx (charge on 1F integrator + B-source;
    boost imposed -> ratchet by construction, no stiff Q-node; verified x20 boost,
    charge conserved). C1/C2 stay Q= caps; return/load = clocked bidirectional
    switches; fire SG3b/SG4b = source-imposed soft-threshold dump (one-way, threshold
    Vstrike, NOT clocked).
    Shuttle now RUNS (~3s, no timestep collapse) and PUMPS (z>1) - both rev-0.1
    blocker modes cleared. Fire is EMERGENT (delta moves 0.192->0.329 with threshold,
    native trend 0.218->0.39) => not XSIM-V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
    [xsim_comparison.csv]
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2026-06-15 feat: geometry-fed pump run on canonical shuttle_core -> GEOM-PUMP-CONFIRMED
    First run of the real buildable geometry (DXF r0.6, Z-stack true-scale caps)
    through the canonical shuttle_core, replacing the campaign placeholder caps.
    Consumer run on geom-shuttle-gate (off main's canonical solver line); not merged.
    shuttle_core.py: ONE additive, default-preserving change (TMD-authorised) — the
    set_device_caps()/reset_device_caps() cap-injection hook + device_caps_selftest
    (+40/-0). Rev-0.3 path byte-identical (hook inert by default): --rev03 anchor
    1.2033, spark C0 T0a 1.2033 / T0b 1.1894 / drift 4.6e-14 all green.
    reference/doubler_core.py and index.html untouched.
    Results (G0-G3), caps con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
    [geom_caps_vs_placeholder.csv, varcap-nodeanalysis-template-r0_6_TMD_layout.dxf]
2026-06-15 sim: first live 5-6 resonator tank + clamp architecture -> TANK-UNDERDRIVEN
    Standalone time-domain RLC + clamp model (design-intent-lock §4-7). Every prior run
    shorted the 5-6 tank; the frozen quasi-static shuttle_core cannot simulate it. This
    module imports NONE of shuttle_core / reference/doubler_core.py / index.html. numpy +
    matplotlib only (hand-rolled RK4, scipy-free; crowbar as a discrete event-dump).
    Branch resonator-sim off geom-shuttle-gate; not merged.
    Tank from the brief (L=169uH, C=1477pF, f0=318.6kHz, Q swept 320/500/900). Drive is
    the open lever: shuttle_core exposes no tank-side delivery, so per-kick E_kick is
    swept {5,20,50,100,300} mJ, anchored by the 88pF island ~17.6 mJ.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
    [resonator_sink_energy.csv]
2026-06-16 sim(r0.2): resonator re-run at revised geometry -> TANK-HOLDS-15kV
    Re-parameterised standalone tank+clamp model for the geometry that closes the r0.1
    17x reach gap. Branch resonator-sim-r2 off resonator-sim; not merged.
    Revised inputs (brief §2-3): island Cx 88->648 pF (now ~ tank C_R -> efficient
    charge-sharing), C_R 1477->960 pF (8 mm garolite), conical-hub L correction
    169->79 uH (cylindrical 169 was a mis-model; f0 318->579 kHz), target 20->15 kV.
    Code moved to sim/resonator_sim.py; brief + hydraulic-philosophy doc saved under
    docs/briefs/. Still standalone (no shuttle_core/doubler_core/index.html imports);
    numpy+matplotlib hand-rolled RK4.
    R0 free-ringdown PASSES (f0 577.9 kHz vs an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
    [resonator_r2_sink.csv]
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2026-06-16 S2 X1/C1: real pump delivery (both maps) -> PUMP-DELIVERS-EASED-ONLY (M2) / UNDERDELIVERS (M1)
    Completes S2 after the TMD coupling decision (run BOTH maps). Read-only consumer of
    the frozen pump driving the unmodified resonator_sim tank; shuttle_core/reference/
    index.html byte-identical (asserted).
    X1 scale-fix: the ideal pump is scale-invariant (eigenvector grows by z, no absolute
    volts), so absolute delivery is set by the operating-point anchor (island fire = design
    HV 20 kV [IR]), not the pump. The two maps BRACKET the 108 mJ reach floor:
    M2 island-dump (eta=0.962 LC transfer of 648/960) -> 124.7 mJ -> EASED-ONLY (16.1 kV)
    M1 rail-increment ((1-1/z)*C_R*V^2) -> 90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
    [s2_E_deliver.csv]
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2026-06-16 S3: S2 reach re-confirm @789 pF + spark tier -> all verdicts green
    One pass validating the v0.10 freeze (C_R 960->789 pF, 12 mm disc). Consumer-only,
    regression-gated; reuses frozen shuttle_core spark machinery + drives the standalone
    resonator_sim tank at 789 pF. Branch s2recheck-s3-spark off freeze-v0.10; not merged.
    shuttle_core/reference/index.html byte-identical (asserted twice).
    Adds presets/G3-geometry-v010.json, sim/s2recheck_s3_spark.py,
    sim/s2recheck-s3-findings.md, sim/s3_spark_traces.png, sim/s3_spark.csv.
    Gates: ring f0/Z0 637.5 kHz/316 ohm; G3 loaded==expect; C0 regression
    (assert_ideal_identity + T0a/T0b/T0c: anchor 1.2033, ideal 1.1894, drift 4.6e-14).
    B1 REACH-CONFIRMED-7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
    [s3_spark.csv]
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2026-06-17 feat: island->tank fire-path ODE + machine eta -> FIRE-PATH-RECOVERS + ENERGY-BALANCE-GAP (escalate)
    The machine-level answer to "mechanical work in vs tank energy out". The stator
    block found the 4-node core only 38.6% efficient (61% C-C tax) but flagged the
    ~89 mJ kick is the island Cx->tank C_R fire, an inductive C-L-C swap.
    sim/fire_tank_transfer.py is a NEW time-domain RK4 ODE (not consumer-only: the
    frozen quasi-static solver shorts the 5-6 tank and cannot do the L-coupled
    dynamics) but all state is consumed from the frozen shuttle_core trace + Block R;
    0 producer edits (shuttle_core/doubler_core/index.html byte-identical, asserted).
    Loop ODE L_eff dI/dt = V_isl - V_tank - V_arc sgn(I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
    [machine_energy_balance.csv]
2026-06-17 feat: island-charging steady-state co-sim -> M2-PARTIAL, resolves M1 vs M2 + the eta>1 paradox
    Sources the island fire self-consistently, replacing the machine-energy-balance
    block's unsourced 130 mJ M2 assumption (which gave the impossible eta_machine =
    7.3 > 1) and resolving the M1-vs-M2 coupling choice deferred since project start
    (s2_coupling.py:14 was BLOCKED on it; run_X1 anchored the island at 20 kV by
    assumption).
    sim/island_charging_cosim.py: steady-state iteration + charge/energy ledger are
    new; consumes the frozen cap topology (Cx 8<->648 pF + 8 pF boss, Ca/Cb 309 pF,
    z=1.307) and the inherited anchors (eta_fire 0.985, W_mech,stator 15.94 mJ,
    useful_per_fire 6.15 mJ). 0 producer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
    [island_charging.csv]
2026-06-17 feat: series-resonator output stage -> SERIES-HOLDS-DC, REACH-DC-15kV in 6 fires
    Re-sims only the post-fire output stage with L_R in SERIES with C_R (5 - L_R -
    junction - C_R - 6), so C_R blocks DC and becomes the DC battery -- dissolving the
    multi-fire accumulation problem the parallel tank (L_R || C_R, shorts DC, rings
    down) could never hold.
    sim/series_resonator_output.py: series fire ODE + accumulation loop (own RK4
    integrator); consumes the inherited island source (Q_isl 1.395 uC, E_fire ~14 mJ,
    W_coll 12.45 mJ @ d0ef6f6), W_mech,stator 15.94 mJ @ 84fcaaa, fire-ODE form @
    05ccf60. 0 producer edits (shuttle_core/reference/index.html byte-identical).
    Key coupling: C_R holds a standing b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
    [series_resonator.csv]
2026-06-17 feat: battery-capacity rev3 -> re-run from DXF+freeze-doc (index.html STALE) -> BINDING=C1/C2 7mm/21kV
    Source correction: rev 2 pulled geometry from index.html and called it
    authoritative -- that is WRONG, index.html is STALE. Re-derived from the r0_6 DXF
    (via ezdxf) + the consolidated freeze-doc varcap-design-freeze-v0.10.md, which
    reverses rev 2's two stale "corrections".
    STANDING CORRECTION (all future work): the geometric reference is the DXF + the
    v0.10 freeze doc; index.html must NOT be used for dimensions (only as a flagged
    [STALE] cross-reference).
    sim/battery_capacity.py rewritten: reads radii + insulation layers from the DXF
    via ezdxf, axial gaps from freeze-doc §3, cross-checke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
    [battery_capacity.csv]
2026-06-17 feat: split L_R + bifilar self-resonant study -> SPLIT do-it; ANTINODE-STRESS-DOMINATES -> simple down-and-back
    Evaluates (A) splitting L_R into two L_R/2 halves at each end of C_R, and (B) the
    per-hub coil topology the split opens (simple down-and-back vs Tesla-bifilar as a
    self-resonant helical resonator).
    sim/coil_topology.py: split + mutual-coupling model + distributed/helical
    self-resonant treatment + 7 self-tests. Geometry from the DXF r0_6 + freeze-doc §3
    (NOT index.html). Inherits L_R 79 uH/C_R 789 pF/f0 637 kHz, the 36-turn conical
    coil, the series ~35 kV node-5 transient, and the rev-3 C1/C2 21 kV binding +
    creepage flag. Ordinary distributed-circuit EE -- no DCCREG. 0 producer e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
    [coil_topology.csv]
2026-06-18 feat: S5 self-consistent operating point + dissipation -> OPERATING-POINT-STABLE + DIELECTRIC-Q-FLAG
    Retires the last assumed drive-side quantity (the absolute island fire voltage)
    by closing the pump<->tank<->clamp loop self-consistently, then adds the
    dissipation budget so the operating point is real, not anchored. Converts S2/S3's
    conditional, anchored reach into a pinned operating point and resolves the
    "15.5 kV cold is tight" caveat. Terminal drive-side characterization (no consumer
    -> no S6).
    Consumer-only: pump scale + island ledger from the frozen shuttle_core (anchor
    z=1.2033); tank + two-tier clamp the UNMODIFIED sim/resonator_sim.py; S5 wraps a
    fixed-point solver around them. sim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
    [s5_operating_point.csv]
2026-06-19 feat: S6 reluctance regen coupling -> COUNTER-ROTATING + REGEN-CLOSES-AT-CORE + REGEN-TRIVIAL
    Decides where the S5 resonator surplus taps into the Block-D C-EMs so it adds
    counter-rotation torque instead of braking. Reluctance torque T=1/2 i^2 dL/dtheta
    is polarity-blind, so only timing decides drive vs brake. Parallel-producer (like
    Block D): reads the Block-D C-EM map + the frozen shuttle_event_angles.csv fire
    clock + the S5 surplus; never feeds solveDoubler4/shuttle_core.
    sim/s6_regen_coupling.py: read-only L(theta) profile + fire-clock overlay + node
    scoring + A0-A4 + 6 named checks; frozen empty-diff asserted (shuttle_core/
    reference/index.html/resonator_sim).
    Results (A0 self-tests +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
    [s6_node_tap_scores.csv]
2026-06-19 feat: S7 expanded-circuit operating point (gating) + drag balance -> OPPOINT-HOLDS + BALANCE-FAILS
    Phase 1 (gating): re-establish the electrical operating point on the EXPANDED
    circuit (split resonator L_R1+C_R+L_R2 + the 12 Cems as an explicit load across
    Ca/Cb). Phase 2 (estimate): drag budget + spin-up / contra-rotation balance.
    Hybrid method (the prior xsim work found the nonlinear shuttle is ngspice-BLOCKED,
    but the galvanic core recovers z and the linear expanded elements are ngspice's
    strength): ngspice for the galvanic regression + the new linear physics
    (split-resonator f0, Cem-branch impedance); frozen resonator_sim for the unchanged
    reach; energy-budget + coil-topology for the no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
    [s7_oppoint_drag.csv]
2026-06-19 feat: S8 unified coupled model + four-destination energy ledger -> SYNERGY-GENERIC
    Replaces the stitched S5-S7 budget (each box solved in isolation, then added) with
    ONE coupled electromechanical model of the whole nest, instrumented to report energy
    by destination per cycle (storage / circulation / output / dissipation), to answer
    the question the piecewise method can't: is coupled E_diss/E_in below the stitched
    prediction, and which coupling carries it? Framing honored -- no new energy (the
    belt sources every watt; a synergy = lower dissipation FRACTION, not gain).
    sim/s8_unified_coupled.py: custom Python integrator (SPICE ruled out -- the shuttle
    is ngspice-blocked). The fast f0 ring tra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
    [s8_energy_partition.csv]
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2026-06-19 recon r0.2: net-for-net vs the committed r0.15 EE schematic -> TOPOLOGY-CONFIRMED
    The r0.15 EE schematic is now committed, so the net-for-net wiring check r0.1/r0.2
    couldn't run (no schematic in the repo -> TOPOLOGY-INCOMPLETE) finally proceeds.
    Commits docs/varcap-nodeanalysis-template-r0.15_TMD_layout.dxf.
    sim/topology_recon.py r0.2: the r0.15 net-tracer (schematic parse + wire-graph by
    endpoint coincidence + symmetry/mislabel audit + the [?]/motor/split-resonator
    confirmation). DXF + frozen read-only (empty-diff asserted).
    Completeness RESOLVED: the schematic carries the 00-CIRCUIT-SCHEMATIC + SCHEMATIC
    layers (drawn wiring), the motor (MECH-CEMS/COIL-CEMS/quadricores + 10 INSERT arrays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
    [topology_edge_list.csv, varcap-nodeanalysis-template-r0.15_TMD_layout.dxf]
2026-06-19 feat: full-sim coupled machine (real shuttle + real Cems) -> FULL-CLOSES (thin, vacuum-gated)
    First true full-machine simulation on the locked r0.15 graph: emergent
    spark-gap doubler + real flying-bucket shuttle (nodes 7/8, retiring the
    W_COLL constant) + fire-ring + 12 real Cem branches (retiring the
    P_CORE/P_MOTOR stub) + quasi-static contra-rotation. Supersedes the
    stitched S5-S8 stack.
    Fixes the three r0.2 defects:
    1. independent torque-integral guard (E_belt_in = W_mech+W_coll+E_drag,
    mechanical side) vs electrically-tallied destinations -> 1.2e-16
    2. emergent output = P_motor - copper - core(flux) = +0.91 W (signed)
    3. real circulation (p-p storage) 22.3 mJ, retiring the pl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
    [full_sim_cem_branches.csv, full_sim_partition.csv]
2026-06-19 feat: geom-extract r0.15 DXF -> overlap(theta)/gap profiles + stations -> GEOMETRY-DRIFTS
    Read-only ezdxf parser turning the dimensioned r0.15 drawing into the
    angle-profiles the torque-resolved sim consumes: per-part geometric A(theta)
    overlap + gap g + fire-station angles, validated against the drawn hatches
    and checked against the model's assumed values. Purely geometric (emits
    A/g/stations, not C/L; nominal C only for the drift check).
    Coordinate reality: each part is drawn 1:1 in its own translated view-frame
    (datum/sector-grid/ref-radii as a (0,0) overlay), stator wedges closed but
    rotor wedges open arc+radial strokes (stitched into closed loops).
    Parser-correctness PASS (hatch re-in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
    [geom_fixed.csv, geom_profiles.csv, geom_stations.csv]
2026-06-19 fix(geom-extract): Cx factor-2 was a drift-check dielectric error, not a drift -> GEOMETRY-CONSISTENT
    The first pass reported GEOMETRY-DRIFTS on a Cx "factor 2" with a two-face
    island reconciliation. That was wrong: the drift-check modelled the 4.0 mm
    drawn gap ENVELOPE as air, but the design island gap is mica-loaded
    (3.0 mm + 0.3 mm mica/face, eps_r 5.4 -> ~2.5 mm effective).
    Calibration confirms the model's own method exactly: G1 88 pF = 6-sector
    r75-232 / 7.6 mm air; 648 pF = 6-sector r75-350 / 2.51 mm-eff. The factor 2
    decomposes exactly (x1.97) into dielectric/gap (x1.59) + bar-fill (x1.24) --
    no two-face, no full-circle-vs-sector error (the parser already measured the
    sectored 148k m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
    [geom_fixed.csv]
2026-06-19 feat: geom-validate gate (island reconcile + A(theta) registration) -> PROFILES-VALIDATED
    The gate before the torque-resolved sim. Two corrections it forced:
    PART A - island reconcile (decided by the AXIAL section, not back-inferred
    from C): the drawn Z-stack shows the island bar with ONE pickup face across
    the 4.0 mm gap and nothing below -> SINGLE-FACE. The brief's "648 = 2x329
    single-face-air, halve to 324" is retired (single-face confirmed AND the gap
    is mica-loaded). Single-face Cx_max ~421-648 pF (model 648 is the top),
    representative ~471 pF (~27% lower). Frozen-shuttle re-derive: W_coll -0..-15%,
    E_fire -0..-11%; fires at 20 kV < 21 kV ceiling throughout -> ISLAND-SINGLE-FACE,
    full-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
    [geom_profiles.csv]
2026-06-19 feat: torque-sim (torque-resolved angular machine) -> GUARD-CLOSES + SELF-SPIN-INDETERMINATE
    The simulation the arc built toward. With PROFILES-VALIDATED, time-step the
    rotor over theta, compute the instantaneous torques from the geometry, and
    build the genuinely INDEPENDENT conservation guard -- retiring the 1.2e-16
    identity the energy-bookkeeping full-sim could not escape. No new energy.
    Two full-sim defects fixed for the dominant terms:
    1. Independent guard: E_belt_in = integral[T_varicap + T_shuttle + T_drag] dtheta
    (instantaneous torques, SOURCE) vs separately-accumulated loss models
    (DEST, not derived from the torque integrals). Closes (28.874 mJ/cycle,
    resid 9.6e-16)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
    [torque_partition.csv, torque_phase.csv]
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2026-06-20 fix(design-synth) r0.2: restore the bus margin; make the canary check the dimension -> CANARY-RESTORED
    One defect, three touch-points: the rotor diameter was reported as the
    active-band diameter (r_out x 2, no bus), the rim was computed at r_out, and
    the canary never asserted the diameter. So the established machine
    "reproduced" at 774 mm instead of its real ~982 mm rotor (R387 active-band
    -> R491 rotor outer after the 27% bus -> R500 plate edge), and I9's rim
    margin was overstated.
    Fixed (geometry-definition only; synthesis logic untouched):
    - BUS_MARGIN = 0.27; rotor_dia_mm = 2*r_out*(1+bus); rotor_outMm for the rim.
    - every reported diameter carries the bus (the search still optimise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
    [synth_compliance.csv, synth_design.csv]
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
